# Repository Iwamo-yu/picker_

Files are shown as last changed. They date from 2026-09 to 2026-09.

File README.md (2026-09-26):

<!-- GENERATED from README.src.md by cad/render_docs.py - edit the source, not this file -->
# picker_: external XYZ capillary picker for an Evident/Olympus IX73

Stage 1 is a **spatial and mechanical feasibility study**: architecture, placement, travel, actuator stacking, capillary approach, interference with the microscope, and 96-well compatibility. There is no control software and there are no manufacturing drawings yet.

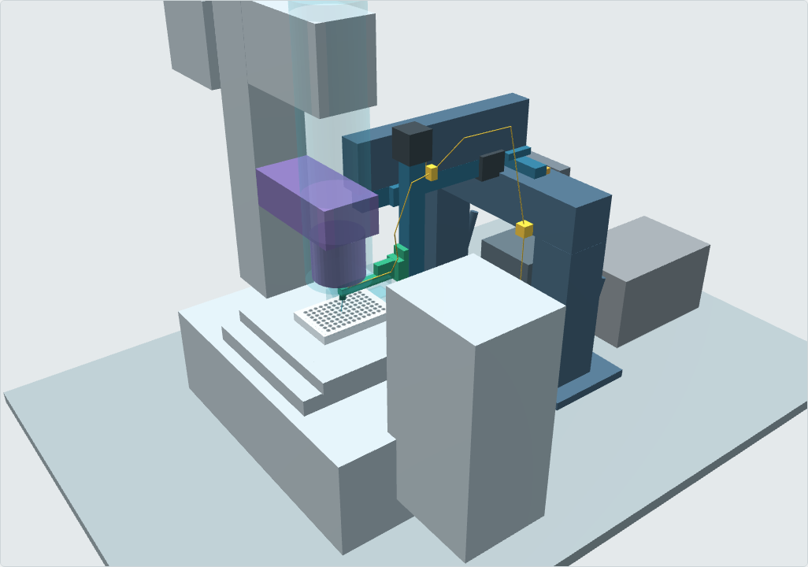
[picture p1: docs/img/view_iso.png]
isometric


## Answer to the main question

> *What is the cleanest mechanically robust way to place an external XYZ capillary picker around an IX73 so that it reliably reaches all wells of a standard 96-well plate without interfering with the microscope?*

**Provisional baseline: workflow W-B plus a side-tower picker.**

- **Workflow W-B.** The IX73 stage, motorised with ≥ 99 × 63 mm travel, brings each source and destination well to the optical axis, so **every pick and dispense is observed** (96/96). This is decision D1; see `docs/09_workflow_D1.md`.
- **Picker.** A side tower bolted to the optical table on the right of the IX73. It is a local XYZ manipulator (100 × 30 × 50 mm, Z with a 1 mm-lead ball screw) whose Z carriage holds a **thin dog-leg arm (120 mm) that reaches under the condenser to a near-vertical (8°) glass capillary**.
- **Independence from the microscope.** Nothing touches the microscope, and the frame unbolts without affecting IX73 alignment.

The stage-fixed alternative **W-A** is kept in the same CAD. Its picker covers the whole plate (150 × 100 mm, arm 180 mm) but observes only 1 well per stage setting.

The layout follows from three constraints found and quantified in this study:

1. **The 96-well limits the angle.** A 1.0 mm capillary reaches the bottom centre of a Corning 7007 U-bottom well (rim Ø6.86 mm, depth 11.30 mm) only within **14.8° of vertical**. At 30° it stops 4.9 mm below the rim, and at 45° 2.7 mm. So 30° and 45° reach **0/96 wells**, whatever the condenser.
2. **A near-vertical capillary must share the optical axis with the condenser.** That fits only under a long-working-distance condenser (**IX-ULWCD, WD 73 mm → 96/96 wells** in W-B, 96/96 in W-A) or with the illumination column tilted back. The IX2-LWUCD (WD 27 mm) and IX2-MLWCD (WD 45 mm) block most positions.
3. **Only the well on the optical axis is seen.** Observed picking of all 96 wells therefore needs the stage to move them there. Evident's IX3-SSU (76 × 52 mm) reaches only 48/96. The manual IX3-SVR (114 × 75) and 120 × 80 motorised stages reach 96/96.

**V1 scope.** V1 supports one plate SKU, **Corning 7007** (96-well U-bottom, no lid during picking), with the 8° head. A target is accepted within 0.5 mm of the well-bottom centre (`docs/09_workflow_D1.md`). Other plates (48-well (Corning 3548), 24-well (Corning 3524), 12-well (Corning 3513), 6-well (Corning 3516)) and their angle blocks are experimental.

**Safe-Z corridor and one Z reference.** The stage moves only while the tip is inside a corridor between the moving plate/stage features and the condenser (19.35–22.18 mm for V1). One physical Z reference switch serves every head (`docs/03_architecture.md` §5).

**Freeze gate.** The condenser outline, stage height and eyepiece envelope are placeholders, because no IX73, condenser or motorised-stage drawing could be retrieved. The clearances near the condenser (4.83–5 mm) are **provisional, not design evidence**. Nothing is frozen until the 10 items M1, M3, M4, M6, M7, M8, M10, M15, M19, M23 are measured (`docs/05_measurement_checklist.md`).

## Deliverables

| # | Required output | File |
|---|---|---|
| 1 | Editable parametric CAD source | `cad/params.py` (all dimensions with provenance), `cad/model.py` (build123d/OpenCascade) |
| 2 | STEP assembly | `cad/out/assembly_WB_R08_IX-ULWCD.step` (baseline W-B); `assembly_WA_{R08,V00,V30,V45}_IX-ULWCD.step` (W-A and angle comparison); `cad/out/zones_{WA,WB}_IX-ULWCD.step` (travel, safe-Z, keep-out, light cone) |
| 3 | Visual CAD preview | `viewer/ix73_picker_viewer.html`, interactive and self-contained (pick a well, angle, condenser; colour by data confidence) |
| 4–7 | Isometric / top / side / front views | 3D renders in `docs/img/view_{iso,top,front,side,head}.png`; dimensioned views in `docs/img/dim_{top,front,side}.png/.svg` |
| 8 | Travel-envelope visualisation | `docs/img/dim_top.png` (tip XY travel over all 96 wells), zones in the viewer and STEP |
| 9 | Collision / interference notes | `docs/02_approach_angle_study.md` §Collision notes; `docs/generated_analysis_tables.md` |
| 10 | 0° / 30° / 45° (+8°) comparison | `docs/02_approach_angle_study.md`, `docs/img/approach_angles.png` |
| 11 | Actuator architecture comparison | `docs/04_actuator_comparison.md` |
| 12 | Recommended overall architecture | `docs/03_architecture.md`; workflow decision D1: `docs/09_workflow_D1.md`, `docs/img/d1_workflows.png` |
| 13 | Missing IX73 measurements | `docs/05_measurement_checklist.md` |
| 14 | Source manifest | `docs/source_manifest.md`, `references/fetch_references.sh` |
| 15 | Electrical block diagram | `docs/06_electrical.md`, `docs/img/electrical_block_diagram.png` |
| 16 | Assumptions | `docs/07_assumptions_and_open_items.md` |
| 17 | Items NOT to finalise yet | `docs/07_assumptions_and_open_items.md` |
| – | Capillary sizing for 100 µm – 1 mm objects | `docs/08_capillary_sizing.md` |
| – | Plate formats (6–96 well) and exchangeable angle blocks (8° / 20° / 30°) | `docs/10_plate_formats_angle_blocks.md` |
| – | Pre-assembly actions (measure / decide / order / fabricate, Japanese) | `docs/11_pre_assembly_actions_ja.md` |
| – | Parts candidates (42 items, from web excerpts; not an order list) | `docs/12_parts_candidates.md`, `docs/parts/candidates.csv`, `docs/parts/research_notes.md` |
| – | Japanese assembly guide (auto-updated) | `docs/assembly_ja/assembly_guide_ja.html` (`python tools/build_all.py`) |
| – | Literature review (5 papers) | `docs/01_literature_review.md` |
| – | Functional diagram (pump → tubing → capillary; PC → XYZ) | `docs/img/functional_diagram.png` |

## Data confidence

Every dimension in `cad/params.py` carries a status (its origin) and, separately, a verification level (`params.verification()`: measured / official file / file retrieved / secondary source / search excerpt / not verified / placeholder / design). The viewer has a DATA ORIGIN mode and a VERIFICATION mode; the dimensioned drawings use the origin colour code:

- **STD / MFR** (green): ANSI/SLAS standards, Evident / Corning / THK / MISUMI / Oriental data.
- **DER / DES** (blue): derived or chosen in this study.
- **APX** (amber): catalogue-class envelope, not a frozen part.
- **PH** (red, hatched): placeholder. Must be measured on the real IX73.

The network policy of the authoring session blocked Zenodo, the publishers, Evident, SLAS and the component vendors. Their values come from search-result excerpts, cross-checked where possible, and are marked as such in the manifest. The two SpheroidPicker GitHub repositories were downloaded and read.

## Rebuild

```bash
pip install build123d matplotlib numpy markdown pytest
python -m pytest tests     # light geometry tests (also run in CI, .github/workflows/check.yml)
python cad/model.py        # STEP + STL + parts.json          (~10 s)
python cad/analysis.py     # well access, light obstruction, clearance sweeps (~10 min)
python cad/views.py        # dimensioned views + diagrams
python cad/render_docs.py  # README.md + docs/*.md from README.src.md + docs/src/*.md
python viewer/build_viewer.py
# or all of the above plus the assembly-guide renders:
python tools/build_all.py            # --fast skips the 8-min clearance sweep
```

`cad/params.py` is the **single source of truth**. Documents are written as templates (`README.src.md`, `docs/src/*.md`) with `{{ KEY }}` numbers from `cad/keynums.py`; edit the templates, never the rendered files. `python cad/render_docs.py --check` fails if a rendered file is stale. Change any value in `params.py` (for example, replace a `PH` with a measured value), rerun, and every figure, table and document number updates.

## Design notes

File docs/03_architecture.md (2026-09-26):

<!-- GENERATED from docs/src/03_architecture.md by cad/render_docs.py - edit the source, not this file -->
# Recommended overall architecture (stage 1, not frozen)

## 1. Recommendation

**Provisional baseline (after D1, see `09_workflow_D1.md`): workflow W-B.** The IX73 stage (motorised, ≥ 99 × 63 mm travel) brings each source and destination well to the optical axis, and the picker works locally at the axis.

The picker itself is a **side tower on the right of the IX73, bolted to the optical table**:

- a fixed Y beam on two posts;
- a Y stage carrying a cantilevered X stage;
- the X stage carrying the Z stage;
- the Z stage carrying a thin dog-leg arm that reaches under an IX-ULWCD condenser to a near-vertical (8°) capillary.

The same frame concept serves W-A (stage fixed) with longer travel and a longer arm. Both are kept in the model. The numbers below are for **W-B unless marked W-A**.

It is the cleanest robust layout for three reasons, each backed by the model:

1. **Only one thin element enters the optical-axis zone.** The arm is 12 × 12 mm for its first 60 mm (W-A: 120 mm). The tall Z actuator stays outside the condenser keep-out in every position, and the moving system clears the IX-ULWCD at all 96 wells at pick height and at safe-Z in both workflows (`09_workflow_D1.md`, `generated_analysis_tables.md`).
2. **The frame avoids every side of the IX73 that is used or unknown.** The operator side and eyepieces (front), the illumination pillar and lamp (rear) and the camera port (left, assumed) all stay clear. The tower axis is 206 mm clear of the body side (W-A: 246 mm), and nothing touches the microscope or its stage.
3. **The stiff, fixed parts are the long ones.** The Y beam is supported at both ends. The cantilevers are the X support beam and the arm (120 mm in W-B, 180 mm in W-A). Both deflect repeatably, and the image calibration absorbs the static sag.

**V1 scope.** V1 supports one plate SKU, **Corning 7007** (96-well U-bottom), with the 8° head (R08). The other plates (48-well (Corning 3548), 24-well (Corning 3524), 12-well (Corning 3513), 6-well (Corning 3516)) and their angle blocks are **experimental** and are not part of the V1 acceptance (`09_workflow_D1.md`).

**Nothing here is frozen** until the 10 freeze-gate items M1, M3, M4, M6, M7, M8, M10, M15, M19, M23 are measured (`09_workflow_D1.md`, freeze gate).

## 2. What is fixed and what moves

| Item | Group | Mounted on | Moves with | Mass carried (estimate, ±30 %) |
|---|---|---|---|---|
| Optical table, IX73, stage, plate, condenser | fixed | – | – | – |
| Base plate (15 mm Al), 2 posts (80 × 80), Y beam (80 × 80), diagonal braces | fixed | table | – | – |
| Y actuator body + motor + home switch, Y cable chain, tubing fixed clamp | fixed | Y beam | – | – |
| Y carriage, X support beam (40 × 80 min.), X actuator + motor + switch, X cable chain | **Y** | Y carriage | Y | **Y carriage carries ≈4.0 kg (W-B, incl. X and Z groups)** |
| X carriage bracket, Z actuator + motor + Z reference switch, tubing clamp #2 | **X** | X carriage | X, Y | **X carriage carries ≈1.3 kg** |
| Z carriage, kinematic break-away mount, dog-leg arm, collet holder, capillary, first 0.3 m of tubing | **Z** | Z carriage | X, Y, Z | **Z carriage carries ≈0.31 kg** |
| Syringe pump (Harvard/Tecan), controller, 24 V PSU | fixed, off-frame | table/shelf | – | – |

The masses come from `params.MASS_APX` (approximate per-part masses for width-20–26 class ball-screw stages with NEMA17 motors) summed over the CAD parts each carriage carries. They are not catalogue values and must be recomputed once part numbers are chosen.

## 3. Axis stacking and travel

Order from the table up: **Y (fixed on beam) → X (cantilever towards the axis) → Z (vertical) → arm → holder → capillary.**

Two different lengths are used throughout, and they are not interchangeable. **Tip travel** is the range the capillary tip must cover. **Actuator stroke** is the catalogue stroke of the linear stage that is bought; it is at least the tip travel and is anchored at the inner (X), front (Y) and lower (Z) end, so the extra stroke grows away from the microscope.

| Axis | W-B tip travel | W-B actuator stroke | W-A tip travel | W-A actuator stroke | Why |
|---|---|---|---|---|---|
| X | **100 mm** (tip -15…+85) | 110 mm | 150 mm | 150 mm | W-B: local calibration ±15 mm plus park / capillary change outside the condenser keep-out. W-A: 99 mm well span + 25.5 mm per side |
| Y | **30 mm** | 50 mm | 100 mm | 100 mm | W-B: local calibration. W-A: 63 mm span + 18.5 mm per side |
| Z | **50 mm** | 80 mm | 50 mm | 80 mm | pick height 3.35 → safe-Z corridor → reference switch → park-only top (capillary change) |

Why Y is the fixed axis and X the cantilever: the side tower gives a naturally long, twice-supported beam in Y. X must reach from the tower to the plate anyway. Swapping them would cantilever the *fixed* beam over the microscope.

## 4. Reaching all 96 wells

- **W-B (baseline).** The stage brings each well to the axis. With the IX3-SVR or a 120 × 80 motorised stage, all 96 wells can be picked *and observed*. The sweep translates plate and stage for every well: 96/96 clear at pick height, 96/96 at safe-Z. The stage moves only while the tip is inside the **safe-Z corridor** (§5). The IX3-SSU (76 × 52) reaches only 48/96.
- **W-A.** Tip travel 150 × 100 covers the 99 × 63 mm well field (96/96 in the sweep), but only 1 well is observed per stage setting. The rest are picked or dispensed blind unless an overview camera is added.

## 5. Z axis: low backlash and no drop on power loss

- **Screw.** Ball screw, lead 1 mm (THK KR20 class, S30), or TR8×2 *single-start, 2 mm lead* in the fallback architecture. Never the common Tr8×8(P2) four-start (8 mm lead), which can back-drive under load (S35).
- **Holding without power.** Back-driving torque from the Z load is T = F·l·η/(2π). With F ≈ 3 N (0.3 kg), l = 1 mm and η ≈ 0.8, T ≈ 0.4 mN·m. A NEMA17's unpowered detent torque is typically about 10–20 mN·m (catalogue class, to be confirmed for the chosen motor), a margin of roughly 25–50×. With a TR8×2 bronze nut, the lead angle (≈5.2° at 7 mm pitch diameter) is below the friction angle (≈6–11° for μ = 0.1–0.2), so the screw is nominally self-locking. Vibration can still creep a marginal self-locking screw.
- **Conclusion.** No brake and no counterbalance are needed at this Z load. Add a brake (for example the Oriental DRS2 brake option, S32) if the holding ratio (motor detent torque ÷ back-driving torque) falls below about 10×. That happens with a Z group above about 1 kg on a 2 mm lead, or with any lead ≥ 5 mm.
- **Resolution.** 1 mm lead / 200 full steps = 5 µm per full step, and 16× microstepping gives 0.31 µm commanded increments. Microstep linearity limits real incremental accuracy to a fraction of a full step, which is sufficient for the ≤5 µm command and 10–20 µm repeatability targets.
- **One physical Z reference.** There is exactly one Z reference switch, fixed on the Z body. It trips when the arm bottom reaches 59.7 mm above the stage datum, i.e. with the head top 2 mm below the lowest condenser front over all supported plates (74.0 mm). Because the holder top sits at the same place on the arm for every angle block, the same switch serves every head; only the tip height at the reference changes (tip at 22.13 mm for R08).
- **Safe-Z corridor.** While the stage moves (W-B) or the picker moves in XY near the axis, the tip must lie in a corridor. Its **lower bound** is the highest moving plate or stage feature plus 5 mm (plate top, or plate-holder clips `STAGE_CLIP_TOP`, M3). Its **upper bound** is the tip height at which the head top is 2 mm under the condenser front. If a configuration has no corridor (upper ≤ lower), it is rejected by the build (`tools/build_all.py --check`). Current values (`generated_analysis_tables.md` §5b):

| Head | Plate | Scope | Lower (tip) | Upper (tip) | Width | Tip at Z reference | Status |
|---|---|---|---|---|---|---|---|
| R08 | 96 U-bottom | V1 | 19.35 | 22.18 | 2.83 | 22.13 | OK |
| V20 | 12-well | experimental | 25.50 | 27.17 | 1.67 | 27.17 | narrow (< 2 mm) |
| V30 | 6-well | experimental | 25.40 | 27.59 | 2.19 | 27.59 | OK |
| V00 | 96 U-bottom | comparison | 19.35 | 21.75 | 2.40 | 21.70 | OK |
| V45 | 96 U-bottom | comparison | 19.35 | 34.64 | 15.29 | 34.59 | OK |

- **Homing.** Z up to the reference switch (this position is inside the corridor), then X to park, then Y. Z goes above the reference only at park (capillary change). The top of the Z stroke is not a safe position near the optical axis.
- **Approach.** Move fast to safe-Z (19.35), then to a pre-contact height about 0.5 mm above the stored well bottom, then land at about 10 µm/s (S23) over the last ~50 µm to the stand-off height (per plate × block × class, `10_…`). A 0.5 mm slow zone would take 50 s per landing, so the slow zone is kept short and the bottom height is calibrated per plate.

## 5b. Stage centring and carriage moments

**Stage centring (W-B).** Every well of the V1 plate reaches the optical axis only if the stage travel centre and the plate position in the holder are within these limits of the axis (`STAGE_AXIS_OFFSET` + `PLATE_HOLDER_OFFSET`, both placeholders until M4 is measured):

| Stage | Travel X × Y | Allowed centring offset X / Y | Current offset | Pass |
|---|---|---|---|---|
| IX3-SVR (manual) | 114 × 75 | ±7.5 / ±6.0 mm | 0.0, 0.0 (PH) | yes |
| IX3-SSU (ultrasonic, motorised) | 76 × 52 | none: travel short by 23 × 11 mm | 0.0, 0.0 (PH) | **no** |
| Maerzhaeuser SCAN IM for IX73 | 120 × 80 | ±10.5 / ±8.5 mm | 0.0, 0.0 (PH) | yes |

**Carriage moments.** Rigid-body static moment plus the moment from 0.5 m/s² acceleration, about each carriage reference, with approximate masses (`params.MASS_APX`). Enter the catalogue allowable moments (`ALLOWABLE_MOMENTS`) once the actuators are chosen; until then the column reads "not entered".

| Carriage | Carried mass (APX) | COM offset from carriage x/y/z | Static + accel. moment Mx, My, Mz (abs.) | Largest | Catalogue allowable |
|---|---|---|---|---|---|
| Z | 0.31 kg | -38 / -0 / -7 mm | 0.00, 0.12, 0.00 N·m | 0.12 N·m | not entered |
| X | 1.34 kg | -13 / -23 / -20 mm | 0.30, 0.19, 0.02 N·m | 0.30 N·m | not entered |
| Y | 3.95 kg | -180 / -9 / 3 mm | 0.36, 6.97, 0.36 N·m | 6.97 N·m | not entered |

The Y carriage carries the X beam and the cantilevered X/Z stack, so it sees the largest moment (≈7.0 N·m). A width-20 class guide may be marginal; compare with the catalogue MY/MP ratings before ordering.

## 6. Capillary holder concept

The holder is a **collet** (split collet with a tapered nut, sized per capillary OD) in a Ø10 × 14 mm envelope, with these features:

- A screw-set **depth stop** above the capillary gives adjustable insertion (default 10 mm grip, 30 mm exposed).
- A side or top liquid port with an O-ring seal on the capillary end-face. The seal is separate from the clamping, so it does not act as friction-only clamping.
- The holder sits in a **V-block seat on the arm** with a flat and a clamp screw. This is the mechanically defined reference surface.
- **Angle** is set by an exchangeable angle block (8° / 20° / 30°) between the kinematic mount and the holder seat: two dowels and one clamp screw. Each plate format has its own block and exposed length (`10_plate_formats_angle_blocks.md`).
- **Tip reproducibility.** The collet and depth stop give roughly ±0.1–0.2 mm (estimate). The real µm-level registration comes from the image-based 3-point re-calibration after every change (S28). The mechanics therefore need only be *stable after clamping*, not µm-reproducible between capillaries.
- **Other ODs**: objects of 100 µm – 1 mm need three capillary classes (OD 1.0 / 1.5 / 2.0; see `08_capillary_sizing.md`). They are handled by swapping the collet insert only, and all keep ≥0.87 mm rim clearance at 8°. The arm, seat and fluid port stay the same.

Commercial alternative: a patch-clamp-style pipette holder with a side port (for example, the Warner holder catalogue in the search results). Many of these clamp with O-rings, which is friction-only and was rejected as the primary fixation. One can be used with a custom depth-stop adapter.

## 7. Tubing and cable routing

**Tubing.** Use PTFE/FEP 1/16" OD (bore to suit, liquid-filled), with no drag chain. Route:

1. Holder top → along the side of the arm, in a clip groove, not on top (it is the closest item to the condenser).
2. Clamp #1 on the Z carriage.
3. Z service loop to clamp #2 on the Z body (X group).
4. X/Y service loop, hung from the X support beam, to the fixed clamp on the frame post.
5. Down the post to the pump on the table (about 1.2 m in total).

Each loop takes the full stroke with a bend radius of at least 25 mm (PTFE kink limit; to be checked for the chosen tubing). Keep the pump, any pinch valve and any pressure tee on the fixed side.

**Cables.** X/Y/Z motor and switch cables leave on the rear (+Y) side of the moving groups and run in two small cable chains (X on the Y group, Y on the frame). That keeps them physically separated from the tubing, which runs on the front (−Y) side. Motor cables should be shielded and separate from the switch cables in the chain.

## 8. Alternatives considered

| Alternative | Verdict | Reason |
|---|---|---|
| Front bridge (beam along X in front of the stage) | rejected | Sits in the eyepiece / observation-tube envelope and the operator's hand space. The eyepiece position is unknown (M12). |
| Rear bridge | rejected | The illumination pillar and lamp housing occupy the rear. |
| Full gantry over the microscope | rejected | The beam must pass above the condenser carrier, which makes Z very long and compliant. |
| Straight holder (no dog-leg) at 30–45° | rejected | Cannot reach 96-well bottoms (`02_…`). |
| **Motorised IX73 stage + short-travel picker (W-B)** | **baseline** | Follows the CellSorter/NanoPick pattern (S22, S24). Every pick and dispense is observed; smaller and stiffer; needs a motorised stage ≥ 99 × 63 mm (not the IX3-SSU). |
| Stage fixed, picker covers the plate (W-A) | kept as alternative | Reaches all wells but observes only the one on the axis; needs an overview camera or blind operation. |
| Pillar tilted back + vertical capillary + fixed LED ring illumination | valid fallback | Removes the condenser conflict entirely. It costs Köhler brightfield during the pick and needs an LED mounted on the frame, not on the head. |

## 9. Alignment and locking interfaces (custom parts that add value)

- **Base plate to table.** Slotted holes on the table grid (M6/25 mm or ¼-20/1", M16). Gives ±15 mm X/Y and ±2° yaw, locked with 6 bolts.
- **Beam height on posts.** Vertical slots plus a jack screw give ±20 mm to match the real stage height (M1). Two clamp bolts per post.
- **X-axis squareness to the plate rows.** Not adjusted mechanically; absorbed by the image calibration (affine transform).
- **Capillary angle.** Exchangeable angle blocks (8° / 20° / 30°), doweled; re-calibrate by image after each change.
- **Removability.** Unbolt the base plate: the IX73 is untouched and its alignment unchanged. Re-installing needs only re-running the image calibration.

## 10. Answers to the system-level questions

| Question | Answer (model reference pose) |
|---|---|
| Where does the gantry sit relative to the IX73? | Right-hand side; tower axis at x = +368 mm (W-A: +408) from the optical axis; posts at y = -115 and +215 mm (W-A: -150 / +230); on its own base plate on the table. |
| Which parts move / stay fixed? | §2 table. The plate and stage move in W-B, driven by the IX73 stage, not by the picker. |
| Moving mass per axis? | Y ≈2.5–3.0 kg (W-B) / 3.0–3.5 kg (W-A), X ≈1.2–1.4 kg, Z ≈0.25–0.35 kg (estimates). |
| How does it reach all 96 wells? | W-B: the stage brings each well to the axis (96/96 observed). W-A: picker travel 150 × 100 (1 observed). |
| Where does the capillary enter the plate? | Vertically from above with an 8° lean towards +X. The holder nose stays ≈19 mm above the plate top at pick height. |
| Where does the tubing leave the head? | Holder top → side of the arm → clamp on the Z carriage (outboard, x ≈ tip + 120 mm). |
| Likely collision regions? | Condenser front (arm and tubing, 4.83 mm at safe-Z with a placeholder condenser); condenser carrier arm vs X support beam (placeholder); well rims (angle); lid; in W-B, the plate moving under the tip if the stage moves below safe-Z. |
| How does the condenser constrain the angle? | Indirectly: the wells force near-vertical, so the capillary must sit below the condenser. With the current head it needs a condenser front ≥ about 70 mm above the well bottom (IX-ULWCD, WD 73 mm) for a 2 mm margin, or the column tilted back. |
| Free space needed around the microscope? | Right side: from the body side (x = 161.5) to x ≈ +458 (W-B) / +498 (W-A) for the frame, plus the pump and controller beyond, if placed there. Nothing on the front, left or rear. |
| Which dimensions still need measuring? | Freeze gate: M1, M3, M4, M6, M7, M8, M10, M15, M19, M23 (`05_measurement_checklist.md`). |

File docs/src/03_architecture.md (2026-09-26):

# Recommended overall architecture (stage 1, not frozen)

## 1. Recommendation

**Provisional baseline (after D1, see `09_workflow_D1.md`): workflow W-B.** The IX73 stage (motorised, ≥ 99 × 63 mm travel) brings each source and destination well to the optical axis, and the picker works locally at the axis.

The picker itself is a **side tower on the right of the IX73, bolted to the optical table**:

- a fixed Y beam on two posts;
- a Y stage carrying a cantilevered X stage;
- the X stage carrying the Z stage;
- the Z stage carrying a thin dog-leg arm that reaches under an IX-ULWCD condenser to a near-vertical (8°) capillary.

The same frame concept serves W-A (stage fixed) with longer travel and a longer arm. Both are kept in the model. The numbers below are for **W-B unless marked W-A**.

It is the cleanest robust layout for three reasons, each backed by the model:

1. **Only one thin element enters the optical-axis zone.** The arm is {{ARM_T_TXT}} for its first {{WB_THIN_L}} mm (W-A: {{WA_THIN_L}} mm). The tall Z actuator stays outside the condenser keep-out in every position, and the moving system clears the IX-ULWCD at all 96 wells at pick height and at safe-Z in both workflows (`09_workflow_D1.md`, `generated_analysis_tables.md`).
2. **The frame avoids every side of the IX73 that is used or unknown.** The operator side and eyepieces (front), the illumination pillar and lamp (rear) and the camera port (left, assumed) all stay clear. The tower axis is {{WB_GAP:.0f}} mm clear of the body side (W-A: {{WA_GAP:.0f}} mm), and nothing touches the microscope or its stage.
3. **The stiff, fixed parts are the long ones.** The Y beam is supported at both ends. The cantilevers are the X support beam and the arm ({{WB_ARM_L}} mm in W-B, {{WA_ARM_L}} mm in W-A). Both deflect repeatably, and the image calibration absorbs the static sag.

**V1 scope.** V1 supports one plate SKU, **{{V1_PLATE_SKU}}** (96-well U-bottom), with the {{V1_THETA:.0f}}° head ({{V1_HEAD}}). The other plates ({{EXPERIMENTAL_PLATES}}) and their angle blocks are **experimental** and are not part of the V1 acceptance (`09_workflow_D1.md`).

**Nothing here is frozen** until the {{FREEZE_GATE_N}} freeze-gate items {{FREEZE_GATE}} are measured (`09_workflow_D1.md`, freeze gate).

## 2. What is fixed and what moves

| Item | Group | Mounted on | Moves with | Mass carried (estimate, ±30 %) |
|---|---|---|---|---|
| Optical table, IX73, stage, plate, condenser | fixed | – | – | – |
| Base plate (15 mm Al), 2 posts (80 × 80), Y beam (80 × 80), diagonal braces | fixed | table | – | – |
| Y actuator body + motor + home switch, Y cable chain, tubing fixed clamp | fixed | Y beam | – | – |
| Y carriage, X support beam (40 × 80 min.), X actuator + motor + switch, X cable chain | **Y** | Y carriage | Y | **Y carriage carries ≈{{MASS_Y:.1f}} kg (W-B, incl. X and Z groups)** |
| X carriage bracket, Z actuator + motor + Z reference switch, tubing clamp #2 | **X** | X carriage | X, Y | **X carriage carries ≈{{MASS_X:.1f}} kg** |
| Z carriage, kinematic break-away mount, dog-leg arm, collet holder, capillary, first 0.3 m of tubing | **Z** | Z carriage | X, Y, Z | **Z carriage carries ≈{{MASS_Z:.2f}} kg** |
| Syringe pump (Harvard/Tecan), controller, 24 V PSU | fixed, off-frame | table/shelf | – | – |

The masses come from `params.MASS_APX` (approximate per-part masses for width-20–26 class ball-screw stages with NEMA17 motors) summed over the CAD parts each carriage carries. They are not catalogue values and must be recomputed once part numbers are chosen.

## 3. Axis stacking and travel

Order from the table up: **Y (fixed on beam) → X (cantilever towards the axis) → Z (vertical) → arm → holder → capillary.**

Two different lengths are used throughout, and they are not interchangeable. **Tip travel** is the range the capillary tip must cover. **Actuator stroke** is the catalogue stroke of the linear stage that is bought; it is at least the tip travel and is anchored at the inner (X), front (Y) and lower (Z) end, so the extra stroke grows away from the microscope.

| Axis | W-B tip travel | W-B actuator stroke | W-A tip travel | W-A actuator stroke | Why |
|---|---|---|---|---|---|
| X | **{{WB_TRAVEL_X}} mm** (tip {{WB_X_MIN}}…+{{WB_X_MAX}}) | {{WB_STROKE_X:.0f}} mm | {{WA_TRAVEL_X}} mm | {{WA_STROKE_X:.0f}} mm | W-B: local calibration ±15 mm plus park / capillary change outside the condenser keep-out. W-A: 99 mm well span + 25.5 mm per side |
| Y | **{{WB_TRAVEL_Y}} mm** | {{WB_STROKE_Y:.0f}} mm | {{WA_TRAVEL_Y}} mm | {{WA_STROKE_Y:.0f}} mm | W-B: local calibration. W-A: 63 mm span + 18.5 mm per side |
| Z | **{{WB_TRAVEL_Z}} mm** | {{WB_STROKE_Z:.0f}} mm | {{WA_TRAVEL_Z}} mm | {{WA_STROKE_Z:.0f}} mm | pick height {{Z_PICK:.2f}} → safe-Z corridor → reference switch → park-only top (capillary change) |

Why Y is the fixed axis and X the cantilever: the side tower gives a naturally long, twice-supported beam in Y. X must reach from the tower to the plate anyway. Swapping them would cantilever the *fixed* beam over the microscope.

## 4. Reaching all 96 wells

- **W-B (baseline).** The stage brings each well to the axis. With the IX3-SVR or a 120 × 80 motorised stage, all 96 wells can be picked *and observed*. The sweep translates plate and stage for every well: {{SW_WB_R08_ULWCD_PICK}}/96 clear at pick height, {{SW_WB_R08_ULWCD_SAFE}}/96 at safe-Z. The stage moves only while the tip is inside the **safe-Z corridor** (§5). The IX3-SSU (76 × 52) reaches only {{D1_WB_SSU_WELLS}}/96.
- **W-A.** Tip travel {{WA_TRAVEL_X}} × {{WA_TRAVEL_Y}} covers the 99 × 63 mm well field ({{SW_WA_R08_ULWCD_PICK}}/96 in the sweep), but only {{D1_WA_OBSERVED}} well is observed per stage setting. The rest are picked or dispensed blind unless an overview camera is added.

## 5. Z axis: low backlash and no drop on power loss

- **Screw.** Ball screw, lead 1 mm (THK KR20 class, S30), or TR8×2 *single-start, 2 mm lead* in the fallback architecture. Never the common Tr8×8(P2) four-start (8 mm lead), which can back-drive under load (S35).
- **Holding without power.** Back-driving torque from the Z load is T = F·l·η/(2π). With F ≈ 3 N (0.3 kg), l = 1 mm and η ≈ 0.8, T ≈ 0.4 mN·m. A NEMA17's unpowered detent torque is typically about 10–20 mN·m (catalogue class, to be confirmed for the chosen motor), a margin of roughly 25–50×. With a TR8×2 bronze nut, the lead angle (≈5.2° at 7 mm pitch diameter) is below the friction angle (≈6–11° for μ = 0.1–0.2), so the screw is nominally self-locking. Vibration can still creep a marginal self-locking screw.
- **Conclusion.** No brake and no counterbalance are needed at this Z load. Add a brake (for example the Oriental DRS2 brake option, S32) if the holding ratio (motor detent torque ÷ back-driving torque) falls below about 10×. That happens with a Z group above about 1 kg on a 2 mm lead, or with any lead ≥ 5 mm.
- **Resolution.** 1 mm lead / 200 full steps = 5 µm per full step, and 16× microstepping gives 0.31 µm commanded increments. Microstep linearity limits real incremental accuracy to a fraction of a full step, which is sufficient for the ≤5 µm command and 10–20 µm repeatability targets.
- **One physical Z reference.** There is exactly one Z reference switch, fixed on the Z body. It trips when the arm bottom reaches {{Z_REF_ARM_BOTTOM:.1f}} mm above the stage datum, i.e. with the head top {{Z_REF_MARGIN:.0f}} mm below the lowest condenser front over all supported plates ({{Z_REF_HEAD_TOP:.1f}} mm). Because the holder top sits at the same place on the arm for every angle block, the same switch serves every head; only the tip height at the reference changes (tip at {{ZREF_TIP_R08:.2f}} mm for {{V1_HEAD}}).
- **Safe-Z corridor.** While the stage moves (W-B) or the picker moves in XY near the axis, the tip must lie in a corridor. Its **lower bound** is the highest moving plate or stage feature plus {{CORRIDOR_LOWER_MARGIN:.0f}} mm (plate top, or plate-holder clips `STAGE_CLIP_TOP`, M3). Its **upper bound** is the tip height at which the head top is {{MIN_MARGIN:.0f}} mm under the condenser front. If a configuration has no corridor (upper ≤ lower), it is rejected by the build (`tools/build_all.py --check`). Current values (`generated_analysis_tables.md` §5b):

{{CORR_TABLE_MD}}

- **Homing.** Z up to the reference switch (this position is inside the corridor), then X to park, then Y. Z goes above the reference only at park (capillary change). The top of the Z stroke is not a safe position near the optical axis.
- **Approach.** Move fast to safe-Z ({{SAFE_Z:.2f}}), then to a pre-contact height about 0.5 mm above the stored well bottom, then land at about 10 µm/s (S23) over the last ~50 µm to the stand-off height (per plate × block × class, `10_…`). A 0.5 mm slow zone would take 50 s per landing, so the slow zone is kept short and the bottom height is calibrated per plate.

## 5b. Stage centring and carriage moments

**Stage centring (W-B).** Every well of the V1 plate reaches the optical axis only if the stage travel centre and the plate position in the holder are within these limits of the axis (`STAGE_AXIS_OFFSET` + `PLATE_HOLDER_OFFSET`, both placeholders until M4 is measured):

{{CENTER_TABLE_MD}}

**Carriage moments.** Rigid-body static moment plus the moment from {{ACCEL:.1f}} m/s² acceleration, about each carriage reference, with approximate masses (`params.MASS_APX`). Enter the catalogue allowable moments (`ALLOWABLE_MOMENTS`) once the actuators are chosen; until then the column reads "not entered".

{{MOMENT_TABLE_MD}}

The Y carriage carries the X beam and the cantilevered X/Z stack, so it sees the largest moment (≈{{MOM_Y:.1f}} N·m). A width-20 class guide may be marginal; compare with the catalogue MY/MP ratings before ordering.

## 6. Capillary holder concept

The holder is a **collet** (split collet with a tapered nut, sized per capillary OD) in a Ø10 × 14 mm envelope, with these features:

- A screw-set **depth stop** above the capillary gives adjustable insertion (default 10 mm grip, 30 mm exposed).
- A side or top liquid port with an O-ring seal on the capillary end-face. The seal is separate from the clamping, so it does not act as friction-only clamping.
- The holder sits in a **V-block seat on the arm** with a flat and a clamp screw. This is the mechanically defined reference surface.
- **Angle** is set by an exchangeable angle block ({{ANGLE_BLOCKS_TXT}}) between the kinematic mount and the holder seat: two dowels and one clamp screw. Each plate format has its own block and exposed length (`10_plate_formats_angle_blocks.md`).
- **Tip reproducibility.** The collet and depth stop give roughly ±0.1–0.2 mm (estimate). The real µm-level registration comes from the image-based 3-point re-calibration after every change (S28). The mechanics therefore need only be *stable after clamping*, not µm-reproducible between capillaries.
- **Other ODs**: objects of 100 µm – 1 mm need three capillary classes (OD 1.0 / 1.5 / 2.0; see `08_capillary_sizing.md`). They are handled by swapping the collet insert only, and all keep ≥0.87 mm rim clearance at 8°. The arm, seat and fluid port stay the same.

Commercial alternative: a patch-clamp-style pipette holder with a side port (for example, the Warner holder catalogue in the search results). Many of these clamp with O-rings, which is friction-only and was rejected as the primary fixation. One can be used with a custom depth-stop adapter.

## 7. Tubing and cable routing

**Tubing.** Use PTFE/FEP 1/16" OD (bore to suit, liquid-filled), with no drag chain. Route:

1. Holder top → along the side of the arm, in a clip groove, not on top (it is the closest item to the condenser).
2. Clamp #1 on the Z carriage.
3. Z service loop to clamp #2 on the Z body (X group).
4. X/Y service loop, hung from the X support beam, to the fixed clamp on the frame post.
5. Down the post to the pump on the table (about 1.2 m in total).

Each loop takes the full stroke with a bend radius of at least 25 mm (PTFE kink limit; to be checked for the chosen tubing). Keep the pump, any pinch valve and any pressure tee on the fixed side.

**Cables.** X/Y/Z motor and switch cables leave on the rear (+Y) side of the moving groups and run in two small cable chains (X on the Y group, Y on the frame). That keeps them physically separated from the tubing, which runs on the front (−Y) side. Motor cables should be shielded and separate from the switch cables in the chain.

## 8. Alternatives considered

| Alternative | Verdict | Reason |
|---|---|---|
| Front bridge (beam along X in front of the stage) | rejected | Sits in the eyepiece / observation-tube envelope and the operator's hand space. The eyepiece position is unknown (M12). |
| Rear bridge | rejected | The illumination pillar and lamp housing occupy the rear. |
| Full gantry over the microscope | rejected | The beam must pass above the condenser carrier, which makes Z very long and compliant. |
| Straight holder (no dog-leg) at 30–45° | rejected | Cannot reach 96-well bottoms (`02_…`). |
| **Motorised IX73 stage + short-travel picker (W-B)** | **baseline** | Follows the CellSorter/NanoPick pattern (S22, S24). Every pick and dispense is observed; smaller and stiffer; needs a motorised stage ≥ 99 × 63 mm (not the IX3-SSU). |
| Stage fixed, picker covers the plate (W-A) | kept as alternative | Reaches all wells but observes only the one on the axis; needs an overview camera or blind operation. |
| Pillar tilted back + vertical capillary + fixed LED ring illumination | valid fallback | Removes the condenser conflict entirely. It costs Köhler brightfield during the pick and needs an LED mounted on the frame, not on the head. |

## 9. Alignment and locking interfaces (custom parts that add value)

- **Base plate to table.** Slotted holes on the table grid (M6/25 mm or ¼-20/1", M16). Gives ±15 mm X/Y and ±2° yaw, locked with 6 bolts.
- **Beam height on posts.** Vertical slots plus a jack screw give ±20 mm to match the real stage height (M1). Two clamp bolts per post.
- **X-axis squareness to the plate rows.** Not adjusted mechanically; absorbed by the image calibration (affine transform).
- **Capillary angle.** Exchangeable angle blocks ({{ANGLE_BLOCKS_TXT}}), doweled; re-calibrate by image after each change.
- **Removability.** Unbolt the base plate: the IX73 is untouched and its alignment unchanged. Re-installing needs only re-running the image calibration.

## 10. Answers to the system-level questions

| Question | Answer (model reference pose) |
|---|---|
| Where does the gantry sit relative to the IX73? | Right-hand side; tower axis at x = +{{WB_TOWER_X}} mm (W-A: +{{WA_TOWER_X}}) from the optical axis; posts at y = {{WB_POST_Y0}} and +{{WB_POST_Y1}} mm (W-A: {{WA_POST_Y0}} / +{{WA_POST_Y1}}); on its own base plate on the table. |
| Which parts move / stay fixed? | §2 table. The plate and stage move in W-B, driven by the IX73 stage, not by the picker. |
| Moving mass per axis? | Y ≈2.5–3.0 kg (W-B) / 3.0–3.5 kg (W-A), X ≈1.2–1.4 kg, Z ≈0.25–0.35 kg (estimates). |
| How does it reach all 96 wells? | W-B: the stage brings each well to the axis ({{D1_WB_OBSERVED}}/96 observed). W-A: picker travel {{WA_TRAVEL_X}} × {{WA_TRAVEL_Y}} ({{D1_WA_OBSERVED}} observed). |
| Where does the capillary enter the plate? | Vertically from above with an 8° lean towards +X. The holder nose stays ≈19 mm above the plate top at pick height. |
| Where does the tubing leave the head? | Holder top → side of the arm → clamp on the Z carriage (outboard, x ≈ tip + {{WB_ARM_L}} mm). |
| Likely collision regions? | Condenser front (arm and tubing, {{SW_WB_R08_ULWCD_SAFE_CLEAR}} mm at safe-Z with a placeholder condenser); condenser carrier arm vs X support beam (placeholder); well rims (angle); lid; in W-B, the plate moving under the tip if the stage moves below safe-Z. |
| How does the condenser constrain the angle? | Indirectly: the wells force near-vertical, so the capillary must sit below the condenser. With the current head it needs a condenser front ≥ about {{WD_REQ:.0f}} mm above the well bottom (IX-ULWCD, WD 73 mm) for a {{MIN_MARGIN:.0f}} mm margin, or the column tilted back. |
| Free space needed around the microscope? | Right side: from the body side (x = {{IX73_HALF_W}}) to x ≈ +{{WB_FOOT_X}} (W-B) / +{{WA_FOOT_X}} (W-A) for the frame, plus the pump and controller beyond, if placed there. Nothing on the front, left or rear. |
| Which dimensions still need measuring? | Freeze gate: {{FREEZE_GATE}} (`05_measurement_checklist.md`). |

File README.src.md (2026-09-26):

# picker_: external XYZ capillary picker for an Evident/Olympus IX73

Stage 1 is a **spatial and mechanical feasibility study**: architecture, placement, travel, actuator stacking, capillary approach, interference with the microscope, and 96-well compatibility. There is no control software and there are no manufacturing drawings yet.

isometric

## Answer to the main question

> *What is the cleanest mechanically robust way to place an external XYZ capillary picker around an IX73 so that it reliably reaches all wells of a standard 96-well plate without interfering with the microscope?*

**Provisional baseline: workflow W-B plus a side-tower picker.**

- **Workflow W-B.** The IX73 stage, motorised with ≥ 99 × 63 mm travel, brings each source and destination well to the optical axis, so **every pick and dispense is observed** ({{D1_WB_OBSERVED}}/96). This is decision D1; see `docs/09_workflow_D1.md`.
- **Picker.** A side tower bolted to the optical table on the right of the IX73. It is a local XYZ manipulator ({{WB_TRAVEL_X}} × {{WB_TRAVEL_Y}} × {{WB_TRAVEL_Z}} mm, Z with a 1 mm-lead ball screw) whose Z carriage holds a **thin dog-leg arm ({{WB_ARM_L}} mm) that reaches under the condenser to a near-vertical (8°) glass capillary**.
- **Independence from the microscope.** Nothing touches the microscope, and the frame unbolts without affecting IX73 alignment.

The stage-fixed alternative **W-A** is kept in the same CAD. Its picker covers the whole plate ({{WA_TRAVEL_X}} × {{WA_TRAVEL_Y}} mm, arm {{WA_ARM_L}} mm) but observes only {{D1_WA_OBSERVED}} well per stage setting.

The layout follows from three constraints found and quantified in this study:

1. **The 96-well limits the angle.** A 1.0 mm capillary reaches the bottom centre of a Corning 7007 U-bottom well (rim Ø6.86 mm, depth 11.30 mm) only within **{{MAX_ANGLE:.1f}}° of vertical**. At 30° it stops {{REACH_30:.1f}} mm below the rim, and at 45° {{REACH_45:.1f}} mm. So 30° and 45° reach **{{SW_WA_V30_ULWCD_PICK}}/96 wells**, whatever the condenser.
2. **A near-vertical capillary must share the optical axis with the condenser.** That fits only under a long-working-distance condenser (**IX-ULWCD, WD 73 mm → {{SW_WB_R08_ULWCD_PICK}}/96 wells** in W-B, {{SW_WA_R08_ULWCD_PICK}}/96 in W-A) or with the illumination column tilted back. The IX2-LWUCD (WD 27 mm) and IX2-MLWCD (WD 45 mm) block most positions.
3. **Only the well on the optical axis is seen.** Observed picking of all 96 wells therefore needs the stage to move them there. Evident's IX3-SSU (76 × 52 mm) reaches only {{D1_WB_SSU_WELLS}}/96. The manual IX3-SVR (114 × 75) and 120 × 80 motorised stages reach 96/96.

**V1 scope.** V1 supports one plate SKU, **{{V1_PLATE_SKU}}** (96-well U-bottom, no lid during picking), with the {{V1_THETA:.0f}}° head. A target is accepted within {{V1_TARGET_R:.1f}} mm of the well-bottom centre (`docs/09_workflow_D1.md`). Other plates ({{EXPERIMENTAL_PLATES}}) and their angle blocks are experimental.

**Safe-Z corridor and one Z reference.** The stage moves only while the tip is inside a corridor between the moving plate/stage features and the condenser ({{CORR_R08_LO:.2f}}–{{CORR_R08_HI:.2f}} mm for V1). One physical Z reference switch serves every head (`docs/03_architecture.md` §5).

**Freeze gate.** The condenser outline, stage height and eyepiece envelope are placeholders, because no IX73, condenser or motorised-stage drawing could be retrieved. The clearances near the condenser ({{SW_WB_R08_ULWCD_SAFE_CLEAR}}–5 mm) are **provisional, not design evidence**. Nothing is frozen until the {{FREEZE_GATE_N}} items {{FREEZE_GATE}} are measured (`docs/05_measurement_checklist.md`).

## Deliverables

| # | Required output | File |
|---|---|---|
| 1 | Editable parametric CAD source | `cad/params.py` (all dimensions with provenance), `cad/model.py` (build123d/OpenCascade) |
| 2 | STEP assembly | `cad/out/assembly_WB_R08_IX-ULWCD.step` (baseline W-B); `assembly_WA_{R08,V00,V30,V45}_IX-ULWCD.step` (W-A and angle comparison); `cad/out/zones_{WA,WB}_IX-ULWCD.step` (travel, safe-Z, keep-out, light cone) |
| 3 | Visual CAD preview | `viewer/ix73_picker_viewer.html`, interactive and self-contained (pick a well, angle, condenser; colour by data confidence) |
| 4–7 | Isometric / top / side / front views | 3D renders in `docs/img/view_{iso,top,front,side,head}.png`; dimensioned views in `docs/img/dim_{top,front,side}.png/.svg` |
| 8 | Travel-envelope visualisation | `docs/img/dim_top.png` (tip XY travel over all 96 wells), zones in the viewer and STEP |
| 9 | Collision / interference notes | `docs/02_approach_angle_study.md` §Collision notes; `docs/generated_analysis_tables.md` |
| 10 | 0° / 30° / 45° (+8°) comparison | `docs/02_approach_angle_study.md`, `docs/img/approach_angles.png` |
| 11 | Actuator architecture comparison | `docs/04_actuator_comparison.md` |
| 12 | Recommended overall architecture | `docs/03_architecture.md`; workflow decision D1: `docs/09_workflow_D1.md`, `docs/img/d1_workflows.png` |
| 13 | Missing IX73 measurements | `docs/05_measurement_checklist.md` |
| 14 | Source manifest | `docs/source_manifest.md`, `references/fetch_references.sh` |
| 15 | Electrical block diagram | `docs/06_electrical.md`, `docs/img/electrical_block_diagram.png` |
| 16 | Assumptions | `docs/07_assumptions_and_open_items.md` |
| 17 | Items NOT to finalise yet | `docs/07_assumptions_and_open_items.md` |
| – | Capillary sizing for 100 µm – 1 mm objects | `docs/08_capillary_sizing.md` |
| – | Plate formats (6–96 well) and exchangeable angle blocks ({{ANGLE_BLOCKS_TXT}}) | `docs/10_plate_formats_angle_blocks.md` |
| – | Pre-assembly actions (measure / decide / order / fabricate, Japanese) | `docs/11_pre_assembly_actions_ja.md` |
| – | Parts candidates (42 items, from web excerpts; not an order list) | `docs/12_parts_candidates.md`, `docs/parts/candidates.csv`, `docs/parts/research_notes.md` |
| – | Japanese assembly guide (auto-updated) | `docs/assembly_ja/assembly_guide_ja.html` (`python tools/build_all.py`) |
| – | Literature review (5 papers) | `docs/01_literature_review.md` |
| – | Functional diagram (pump → tubing → capillary; PC → XYZ) | `docs/img/functional_diagram.png` |

## Data confidence

Every dimension in `cad/params.py` carries a status (its origin) and, separately, a verification level (`params.verification()`: measured / official file / file retrieved / secondary source / search excerpt / not verified / placeholder / design). The viewer has a DATA ORIGIN mode and a VERIFICATION mode; the dimensioned drawings use the origin colour code:

- **STD / MFR** (green): ANSI/SLAS standards, Evident / Corning / THK / MISUMI / Oriental data.
- **DER / DES** (blue): derived or chosen in this study.
- **APX** (amber): catalogue-class envelope, not a frozen part.
- **PH** (red, hatched): placeholder. Must be measured on the real IX73.

The network policy of the authoring session blocked Zenodo, the publishers, Evident, SLAS and the component vendors. Their values come from search-result excerpts, cross-checked where possible, and are marked as such in the manifest. The two SpheroidPicker GitHub repositories were downloaded and read.

## Rebuild

```bash
pip install build123d matplotlib numpy markdown pytest
python -m pytest tests     # light geometry tests (also run in CI, .github/workflows/check.yml)
python cad/model.py        # STEP + STL + parts.json          (~10 s)
python cad/analysis.py     # well access, light obstruction, clearance sweeps (~10 min)
python cad/views.py        # dimensioned views + diagrams
python cad/render_docs.py  # README.md + docs/*.md from README.src.md + docs/src/*.md
python viewer/build_viewer.py
# or all of the above plus the assembly-guide renders:
python tools/build_all.py            # --fast skips the 8-min clearance sweep
```

`cad/params.py` is the **single source of truth**. Documents are written as templates (`README.src.md`, `docs/src/*.md`) with `{{ KEY }}` numbers from `cad/keynums.py`; edit the templates, never the rendered files. `python cad/render_docs.py --check` fails if a rendered file is stale. Change any value in `params.py` (for example, replace a `PH` with a measured value), rerun, and every figure, table and document number updates.

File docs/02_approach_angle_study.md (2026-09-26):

<!-- GENERATED from docs/src/02_approach_angle_study.md by cad/render_docs.py - edit the source, not this file -->
# Capillary approach: 0° vs 8° vs 30° vs 45°, plus collision and interference notes

Figures: `img/approach_angles.png`, `img/view_head.png`, `img/dim_front.png`. The raw numbers are in `generated_analysis_tables.md`, produced by `cad/analysis.py`.

## Conclusion

The capillary's last segment must be **near-vertical (0–12°)**. The binding constraint is the 96-well itself, not the condenser. A near-vertical capillary then has to share the space on the optical axis with the condenser. That works only if (a) the condenser has a long working distance (IX-ULWCD, WD 73 mm) and the picker reaches in with a thin horizontal "dog-leg" arm below it, or (b) the illumination column is tilted back during picking. With the IX2-LWUCD (WD 27 mm) no angle works. **8° with a dog-leg arm** is the recommended geometry for 96-well plates. The angle is set by exchangeable angle blocks (8° / 20° / 30°), one per plate format (`10_plate_formats_angle_blocks.md`), not by a continuous tilt.

## Method

Every angle uses the same external frame and the same outboard Z position, with the W-A frame (180 mm arm, picker covering the plate; the W-B frame gives the same angle results at the optical axis). Only the capillary/holder angle changes, so the comparison isolates the effect of angle. Three checks were run:

1. **Well access (analytic).** Corning 7007 U-bottom: rim Ø6.86 mm, depth 11.30 mm (S13). Capillary OD 1.0 mm, tip 0.3 mm above the well bottom.
2. **Clearance sweep (OpenCascade minimum distance).** All 96 wells at pick height and at safe-Z (the lower bound of the safe-Z corridor: highest moving plate or clip feature + 5 mm), plus a 35-point grid over the full 150 × 100 travel at safe-Z and at the top of the Z stroke. Moving parts are checked against the IX73 envelope, the condensers, the plate and the pump.
3. **Illumination obstruction (analytic).** Fraction of the condenser light cone blocked by the Ø10 holder at its nose height.

## Results

| Criterion | 0° | **8° (rec.)** | 30° | 45° |
|---|---|---|---|---|
| Rim clearance, tip at well-bottom centre | +2.93 mm | **+1.38 mm** | -3.50 mm (hits rim) | -8.28 mm (hits rim) |
| Deepest centred reach below the rim | full (11.3 mm) | **full** | 4.9 mm | 2.7 mm |
| Wells reachable at pick height, IX-ULWCD | 96/96 | **96/96** | 0/96 | 0/96 |
| Wells reachable at pick height, IX2-LWUCD | 10/96 | 16/96 | 0/96 | 0/96 |
| Wells reachable at pick height, pillar tilted back | 96/96 | **96/96** | 0/96 | 0/96 |
| Illumination blocked by holder, condenser NA 0.1 / 0.3 | 100 % / 28 % | 61 % / 28 % | 0 % / 0 % | 0 % / 0 % |
| Tip visible beside holder in transmitted light | no (coaxial) | partly | yes | yes |
| Cantilever from holder to tip (exposed glass) | 30 mm | 30 mm | 30 mm | 30 mm |
| Lateral tip compliance from tubing/drag forces | lowest | low | medium (bending ∝ sin θ) | highest |
| Tubing exit | vertical, turns into arm | same | along capillary axis, higher | lowest, near plate |
| Maximum angle for bottom-centre access | | 14.8° (no margin) | | |

**Reading the table.**

- **30° and 45° fail** for any standard 96-well plate. The shaft meets the rim long before the tip reaches the bottom. That holds whatever condenser is fitted. An angled capillary also cannot follow an object off-centre on the far side of a U-bottom.
- **0° is geometrically best** for the wells, but the holder sits coaxially above the tip. At low condenser NA it blocks the whole light cone, so transmitted-light imaging during the landing is lost.
- **8°** keeps a 1.38 mm rim margin and moves the holder about 4 mm off the axis. Including the arm, the head still blocks about a third of the NA 0.3 cone at 8° (ray test, `generated_analysis_tables.md` §2), so the image is darker during landing but the tip remains visible beside the holder. The Zhao et al. 45° mount (S23) is correct for open droplets but not for wells.

The illumination figures are an obstruction estimate, not an optical simulation. **Test M18** (a Ø10 rod at 30–45 mm above focus, 4× and 10×) decides whether the 8° block is enough for 96-well work or whether a 10–12° block should be added.

## Condenser constraint

Condenser fronts are placed at well bottom + WD, with WD from manufacturer data (S03, S04). Condenser diameter and body are **placeholders** (Ø80), so all numbers below move once M6–M8 are measured.

| Condenser | WD (MFR) | front above plate top | Result with dog-leg arm (12 mm thick) |
|---|---|---|---|
| IX2-LWUCD | 27 mm | ≈15.7 mm | arm collides at pick height near the axis: **unusable** |
| IX2-MLWCD | 45 mm | ≈33.7 mm | arm collides at pick height near the axis: **unusable** |
| **IX-ULWCD** | 73 mm | ≈61.7 mm | W-A 96/96, W-B 96/96 at pick height; minimum clearance 4.83 mm at safe-Z (tubing on the arm vs condenser front) |
| none (column tilted back) | – | – | no constraint; needs alternative illumination during picking |

## Collision and interference notes

1. **Condenser.** This is the dominant hazard. Under the IX-ULWCD the Z stroke **above the reference height is blocked near the axis**. W-A: 20 of 35 grid points at top-Z are clear; W-B: 15 of 35. In W-A the arm reaches 120 mm towards +X, so collisions also occur with the tip *outside* a simple cylinder around the axis. The control rule is therefore: **Z may go above the reference switch height only at the park position** (X ≥ park), and homing lifts Z to the reference switch first (`06_electrical.md`). Capillary changes happen at park.
2. **Arm length.** The thin section of the arm must extend from the tip by |tip x min| + condenser radius + margin: 120 mm in W-A, 60 mm in W-B (computed in `params.layout`). (During the W-A iteration, a 60 mm thin section collided at safe-Z in columns 1–3. The sweep caught it, and the rule above was derived from it.) The tall Z actuator stays outboard of the condenser in every position.
3. **Tubing on the arm.** It is the closest item to the condenser (4.83 mm). Route it along the side of the arm, not on top.
4. **Well walls.** They are the binding constraint on angle (above). The OCC sweep and the analytic check agree: 30° and 45° give 0/96.
5. **Plate lid.** The model assumes no lid. A lid adds about 2 mm (Corning 7007 is 0.650 in = 16.5 mm high with lid, against 14.35 mm without). Lid removal belongs in the workflow.
6. **Stage and plate holder clips.** These are unknown (M3). The arm underside is ≈41 mm above the stage at pick height and ≈57 mm at safe-Z, so it is not critical.
7. **Objective and turret.** They lie below the stage; the picker cannot reach them because nothing moves below z = 0. The risk is to the plate bottom, not the objective: a tip driven through a thin plate bottom would load the plate. Limit this with a firmware Z floor at the **measured** well bottom + r·sin θ + 0.1 mm per plate × block × capillary class (the lowest edge of a tilted square-cut tip), never below the bottom.
8. **Microscope frame.** The closest fixed IX73 item to the frame is the body side at x = +161.5 mm. The tower axis is at +408 mm in W-A (246 mm gap) and +368 mm in W-B (206 mm gap). The X support beam passes over the stage at z ≥ 180 mm; the condenser carrier arm is at x = ±45 mm (placeholder), and the X actuator's inner end is at x = 60 mm (20 mm beyond the condenser radius). **This gap is a placeholder result and must be re-checked after M7.**
9. **Eyepieces / observation tube.** The frame does not use the operator side. A front bridge was rejected because it would sit in the (unknown, M12) eyepiece envelope and in the operator's hand space.
10. **Break-away mount.** The arm hangs on a magnet-preloaded kinematic mount (e.g. Thorlabs KB25/M, about 16 N holding force, P12). It is a **kinematic repositioner, not a force limiter**: its release force at the tip is about 1.67 N. That protects the plate, stage and condenser from a stalled axis (below the 5 N plate limit, placeholder), but **not the capillary**, whose estimated lateral breaking force is 0.15–1.18 N (`06_electrical.md`). Treat capillaries as consumables in a crash, and re-calibrate after any detach. A compliant low-force stage at the holder is open decision D9.

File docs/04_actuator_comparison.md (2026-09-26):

<!-- GENERATED from docs/src/04_actuator_comparison.md by cad/render_docs.py - edit the source, not this file -->
# Preliminary actuator architecture comparison

Values marked (S..) come from the source manifest. Values marked ~ are typical catalogue-class figures that were **not verified in this session** and must be checked against the chosen part's datasheet before ordering.

| Criterion | **A. Industrial compact ball-screw stages** (THK KR20/KR26, MISUMI LX20/LX26, Oriental DRS2 for Z) | **B. Low-cost integrated stages** (FUYU FSL30/FSK30, generic MGN12 + SFU08/12 ball screw + NEMA17) | **C. Custom** (MGN12H rail + Tr8×2 single-start lead screw + NEMA17) |
|---|---|---|---|
| Travel availability | KR20: 30–130 mm (S30), so Z 50 mm and X 100 mm (W-B) fit; W-A's X 150 mm needs KR26/LX26; LX26: lead 2/5 mm (S31) | 50–300 mm (S33) | any |
| Repeatability | ~±0.003 mm (precision grade) to ~±0.01 mm; DRS2 ±0.003 (ground) / ±0.01 (rolled) (S32) | position accuracy 0.05 mm quoted (S33); repeatability ~±0.01–0.02, batch dependent | ~±0.01–0.02 mm with single-direction approach; depends on assembly |
| Backlash | ~≤0.02 mm, preloaded nut options | ~0.01–0.03 mm | 0.05–0.1 mm with a plain brass nut; ~0.01–0.02 with an anti-backlash POM nut (wears) |
| Lead / resolution | 1 or 2 mm, so 5–10 µm per full step | 1–5 mm typical | 2 mm, so 10 µm per full step |
| Rigidity | high: U-rail with integrated guide (S30) | medium: extruded body, small blocks | medium: depends on the base plate you design |
| Size (width class) | 20–26 mm | 30–40 mm | 27 mm carriage, plus screw offset |
| Moving mass | low–medium | medium | low |
| Assembly effort | bolt-on; motor bracket supplied | bolt-on | high: alignment of screw, rail and bearings |
| Availability (Japan) | good via MISUMI/THK/Oriental distributors | online marketplaces; lead time and QC vary | all parts common |
| Serviceability | documented, grease ports, spares | limited documentation | fully user-serviceable |
| Suitability around IX73 | best: compact bodies keep the X cantilever light and the Z envelope narrow | acceptable for Y (fixed beam); weaker as a cantilevered X | acceptable for Y; weakest for Z (backlash) |
| Typical cost (rough) | highest (~JPY 50–120k per axis) | lowest | lowest in parts, highest in labour |

## Recommendation (to be frozen only after the geometry is validated)

"Tip travel" is what the capillary tip must cover; "actuator stroke" is the catalogue stroke bought, which is at least the tip travel (`03_architecture.md` §3).

- **Z: architecture A, 1 mm lead ball screw** (THK KR20 class; tip travel 50 mm, catalogue actuator stroke 80 mm in the model), or an Oriental DRS2 guide type with brake if a closed-loop absolute axis is preferred. Z sets landing accuracy and must not drop, so this is where the money should go.
- **X: architecture A** (KR20/LX26 class, lead 1–2 mm; tip travel 100 mm in W-B → actuator stroke 110 mm, tip travel 150 mm in W-A → 150 mm). It is the cantilevered axis, so body stiffness and low mass matter most.
- **Y: A or B** (tip travel 30 mm in W-B → actuator stroke 50 mm). It is fixed on a supported beam, so a good integrated stage from B is acceptable, but its carriage carries the X and Z groups (≈4.0 kg, largest moment ≈7.0 N·m, `03_architecture.md` §5b): check the catalogue moment ratings. Choose A if one supplier and consistent documentation matter.
- **Architecture C** is kept as a comparison and fallback. It is appropriate only if lead times block A/B. In that case, use a Tr8×2 single-start screw (2 mm lead, **not** Tr8×8), an anti-backlash nut, a fixed-floating bearing arrangement, and always approach from one direction.

This mix fits the stated budget order (about JPY 200k, cost secondary) with A on X and Z. The exact part numbers are **not** frozen (see `07_…`).

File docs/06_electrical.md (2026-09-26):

<!-- GENERATED from docs/src/06_electrical.md by cad/render_docs.py - edit the source, not this file -->
# Preliminary electrical architecture (not frozen; no software in this stage)

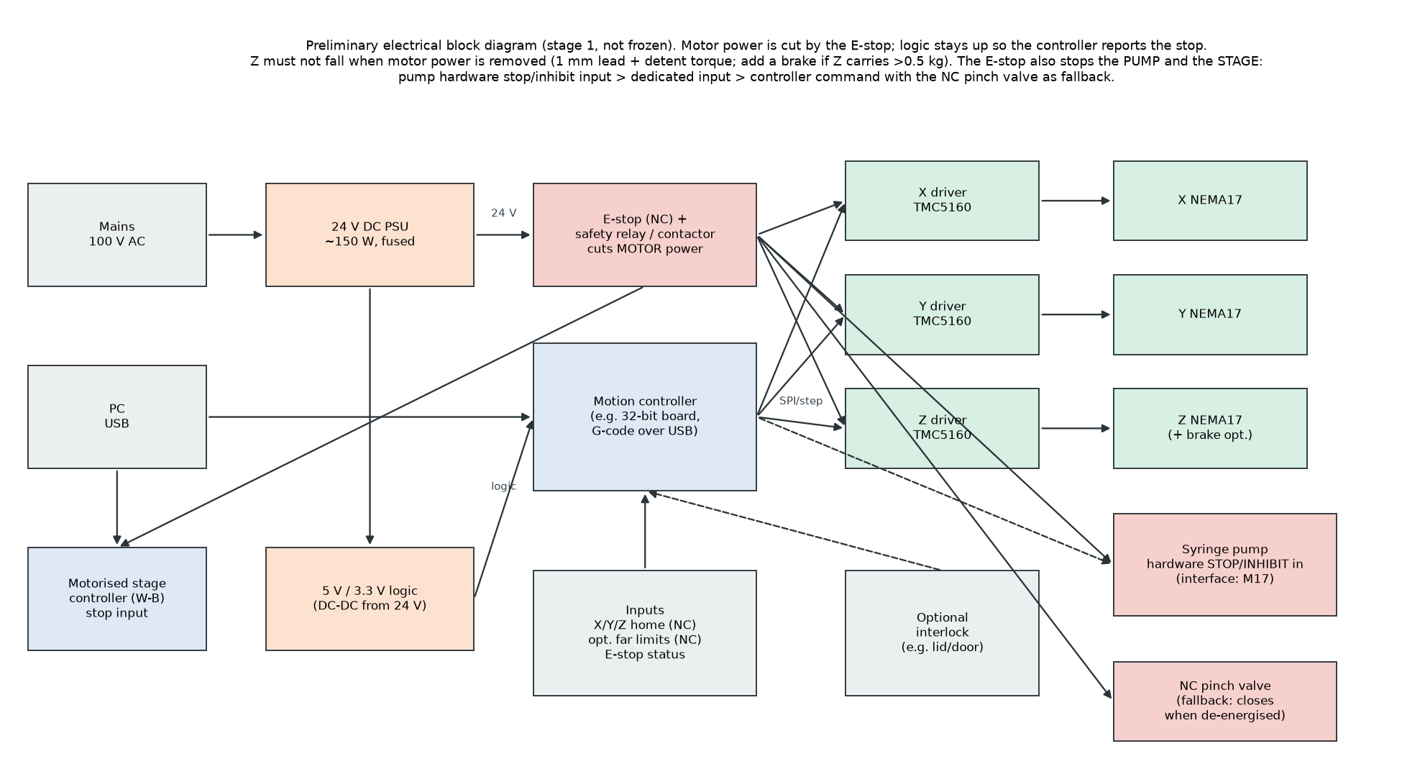
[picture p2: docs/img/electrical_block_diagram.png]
electrical block diagram


```mermaid
flowchart LR
  AC[Mains 100 V AC] --> PSU[24 V DC PSU ~150 W, fused]
  PSU --> ES[E-stop NC + safety relay / contactor<br/>cuts MOTOR power only]
  PSU --> LOGIC[5 V / 3.3 V logic]
  PC[PC - USB] --> CTL[Motion controller<br/>G-code / serial]
  LOGIC --> CTL
  ES --> DX[X driver TMC5160] & DY[Y driver TMC5160] & DZ[Z driver TMC5160]
  CTL -- SPI + step/dir --> DX & DY & DZ
  DX --> MX[X NEMA17]
  DY --> MY[Y NEMA17]
  DZ --> MZ[Z NEMA17 + optional brake]
  SW[X/Y/Z home NC<br/>optional far limits NC<br/>E-stop status] --> CTL
  IL[optional interlock] -.-> CTL
  PC -. RS-232/USB .-> PUMP[Syringe pump<br/>own PSU, off-frame]
  ES -- hardware stop / inhibit --> PUMP
  CTL -. stop command .-> PUMP
  ES -- power --> PV[NC pinch valve<br/>fallback]
  PC --> STG[Motorised stage controller W-B]
  ES -- stop input --> STG
```

The main decisions are below.

**Driver class.** TMC5160 rather than TMC2209. The TMC5160 has external MOSFETs, so it runs 24 V NEMA17s at 1.5–2 A with headroom. It has SPI configuration and diagnostics, and stealthChop gives smooth low-speed Z landing. The TMC2209 is adequate electrically for small NEMA17s, but it runs near its thermal limit at 1.5 A and is configured over UART.

**Controller.** Any PC-accessible, G-code-speaking 32-bit motion board that exposes SPI to TMC5160 drivers and ≥6 NC inputs. An industrial alternative is to use the actuator vendor's own drivers, such as the Oriental AZ driver for a DRS2 Z axis. This follows the SpheroidPicker precedent of a G-code serial controller (S28).

**Home and reference switches.** All are normally-closed (fail-safe), so a broken wire reads as "triggered".
- X: outboard end. Y: front end.
- Z: **two switches**.
  - The **reference switch** is one physical switch on the Z body. It trips when the arm bottom is at 59.7 mm above the stage datum, i.e. with the head top 2 mm below the lowest condenser front over all supported plates. It is set from M8 at installation. At that height the arm clears the condenser at every XY. Because the angle blocks change only the tip, not the arm, the same switch serves all heads; the tip lies inside each head's safe-Z corridor: 22.13 / 27.17 / 27.59 mm above the stage top for the 8° / 20° / 30° blocks (corridors in `03_architecture.md` §5).
  - The **top limit switch** is an over-travel stop only. It is *not* a safe position: near the optical axis, Z at the top drives the arm into the condenser.

**Homing order.** Z rises slowly to the reference switch (inside the corridor). X then moves to park (+85 mm, outside the condenser). Only then may Z go higher, and Y homes. After a power loss the tip may still be in a well; this order lifts it vertically out of the well without dragging it sideways and without reaching the condenser. A closed-loop absolute Z (D5, e.g. DRS2) makes this recovery independent of switches.

**Far limits.** Optional NC switches plus firmware soft limits. The actuators' own mechanical end stops are the hard limit.

**E-stop.** It removes motor power through a contactor. Logic stays powered so the controller latches and reports the fault. Z does not fall (see `03_architecture.md` §5). The E-stop must also stop **the pump and the motorised stage**, because a running pump keeps aspirating or dispensing and a moving stage drags the plate under the tip.

**Pump stop on E-stop (issue #8).** The pump keeps its own power supply, but its motion must stop on E-stop. Use the first option the chosen pump supports, in this order:

1. a **hardware stop / inhibit input** on the pump, wired to a spare NC contact of the safety relay;
2. a dedicated digital "stop" or "external trigger" input, driven by the relay;
3. a **controller stop command** over RS-232/USB **plus** a normally-closed pinch valve on the line, powered through the E-stop circuit, so the line is closed when power drops even if the command is lost.

Cutting the pump's mains is the last resort: some pumps lose their position or state and may not stop the plunger cleanly. M17 records which interface the lab's pump offers.

**Motorised stage on E-stop (W-B).** The stage controller's stop/enable input is wired to the relay the same way. If it has none, the stage motor supply is switched by the contactor.

**Restart and recovery.** Releasing the E-stop does not restart anything. The operator acknowledges the fault on the PC. The controller then re-homes Z to the reference (tip vertically out of the well), X to park, then Y. The pump is re-enabled last, after the tubing and the capillary have been inspected. A capillary that was in a well at the stop is treated as possibly broken (see break-away below).

**Break-away mount is a kinematic repositioner, not a force limiter.** The magnetic kinematic mount under the arm lets the arm come off in a crash and go back on to about the same place. It does **not** limit the force on the capillary: at a hold force of about 16 N it releases at about 1.67 N at the tip, above the estimated lateral breaking force of every capillary class (0.15–1.18 N). It does protect the plate (below 5 N, placeholder):

| Capillary | OD / ID | Lateral break force at the tip (est.) | Mount release force at the tip | Capillary protected | Plate protected |
|---|---|---|---|---|---|
| S  (100-300 um) | 1.00 / 0.58 | 0.15 N | 1.67 N | **no** | yes |
| M  (300-600 um) | 1.50 / 0.84 | 0.50 N | 1.67 N | **no** | yes |
| L  (600-800 um) | 2.00 / 1.12 | 1.18 N | 1.67 N | **no** | yes |
| L' (800-1000 um) | 2.00 / 1.56 | 0.82 N | 1.67 N | **no** | yes |

Capillaries are therefore consumables in a crash. If the capillary itself must survive, a compliant or low-force stage is needed at the holder (a spring-loaded flexure that deflects at well below 0.15 N), or current/torque-limited Z landing with contact detection. This is left open (not V1).

**Wiring.** Motor cables shielded; switch cables in separate, twisted pairs; both in the cable chains on the rear side of the moving groups; tubing on the front side (`03_…` §7).

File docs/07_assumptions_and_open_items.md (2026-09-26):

<!-- GENERATED from docs/src/07_assumptions_and_open_items.md by cad/render_docs.py - edit the source, not this file -->
# Assumptions, open decisions and items NOT to finalise yet

## Assumptions made in this iteration

1. Coordinate frame: origin at the optical axis on the stage-insert top; the plate is centred on the axis at the "reference stage position" with A1 at rear-left.
2. Stage top is 200 mm above the table. **Placeholder** (M1). The frame height scales with it.
3. The IX73 body is centred on the optical axis in X. The body front face is at y = −235 mm. The pillar and condenser arm are ±45 mm wide. The condenser is a conservative Ø80 × 70 mm cylinder (`COND_PROFILE`; the real IX-ULWCD front is probably narrower). The frame is the 1-deck configuration, 656 mm high (`IX73_DECKS`; a 2-deck IX73P2F is about 721 mm, unconfirmed). **All placeholders** (M5–M9). No official IX73, condenser or motorised-stage drawing could be retrieved.
4. Condenser working distances are the manufacturer values (27/45/73 mm), measured from the well-bottom plane. The real front-lens height at the focus used may differ by a few mm (M8).
5. **V1 plate: Corning 7007 only** (U-bottom ULA, rim Ø6.86, depth 11.30), with no lid during picking. Targets within 0.5 mm of the well-bottom centre. Other plates are experimental.
6. Capillary: OD 1.0 / ID 0.6 / L 40, gripped 10 mm, 30 mm exposed. Tip stand-off 0.3 mm above the well bottom (model value; the process value is set experimentally).
7. The IX73 stage is modelled as the manual IX3-SVR (114 × 75 mm). In W-B it is replaced by, or treated as, a motorised stage with ≥ 99 × 63 mm travel that carries only the plate. The picker never loads the stage.
8. The table has free space to the right of the microscope to about +498 mm (W-A) / +458 mm (W-B) from the optical axis, plus the pump and controller beyond.
9. Actuator envelopes are width-26 class ball-screw stages; masses are ±30 % estimates.
10. Deflections are hand estimates (aluminium, simple beams); no FEA.
11. The pump, tubing and fluid volumes do not constrain the mechanics beyond a 1/16" tubing path with ≥25 mm bend radius.

## Open decisions (owner: user)

| ID | Decision | Options | Effect |
|---|---|---|---|
| D1 | Workflow | **provisional: W-B** (stage moves wells to the axis; all picks observed) vs W-A (stage fixed, blind outside the axis) — `09_workflow_D1.md` | picker travel, motorised stage ≥ 99 × 63 mm (not IX3-SSU) |
| D2 | Condenser during picking | IX-ULWCD (buy or borrow if not present) vs tilt column back + LED ring | whether the dog-leg arm is needed |
| D3 | Angle-block set | 8° / 20° / 30° per plate format; add a 10–12° block only if test M18 requires it | angle blocks, calibration |
| D4 | Side of tower | right (default) vs left (mirror) | after M12/M13/M15 |
| D5 | Z actuator type | open-loop ball screw vs closed-loop absolute (DRS2) with brake | cost, homing strategy |
| D6 | Capillary classes to stock | S/M/L (OD 1.0/1.5/2.0) vs fewer; thin-wall 2.0 for 1 mm objects | collet inserts, syringe size |
| D8 | 48-well with OD 1.5/2.0 capillaries | 8° block (reaches under 50 % of the bottom) vs a 0° block (reaches more, blocks most transmitted light) vs no 48-well use for large objects | angle-block set |
| D9 | Capillary protection in a crash | accept capillaries as consumables (V1: the break-away mount protects only the plate) vs a compliant low-force holder stage vs torque-limited landing with contact detection | holder design, cost |
| D7 | Motorised stage for W-B | Märzhäuser SCAN IM 120 × 80 class or equivalent (IX3-SSU 76 × 52 is too small) | cost, controller integration |

## Items that should NOT be finalised yet

Freeze gate: nothing below is frozen before the 10 items M1, M3, M4, M6, M7, M8, M10, M15, M19, M23 are measured and entered in `cad/params.py`.

- Actuator part numbers, strokes rounded to catalogue steps, motor frame lengths.
- Bracket geometry, fasteners, dowel positions, machining tolerances and drawings.
- Frame section sizes (80 × 80 posts/beam, 40 × 80 X support) beyond the envelope level. They need the real height (M1) and a stiffness check.
- Dog-leg arm length (120 mm in W-B, 180 mm in W-A) and thickness (12 × 12 mm). Both depend on the condenser diameter and height (M6–M8).
- Holder design (collet size, port type, kinematic mount). No commercial holder was found that positively grips OD 1.0/1.5/2.0 with a side port; the lead candidate is a custom body with ER8 collets (P10). Its nut may exceed the Ø10 mm holder envelope used in the analysis (unverified). If so, re-run `analysis.py` with the larger `HOLDER_D`.
- Budget: industrial stages on all three axes are estimated at roughly JPY 250–350k for the picker (parts research, unverified); a cheaper integrated Y stage keeps it near JPY 200k.
- IX-ULWCD availability (P09): one excerpt reports it as not available in some regions. Confirm with Evident Japan first.
- Base-plate hole pattern (M16).
- Tubing type, bore and length (pump choice M17, dead volume).
- Cable chain sizes, connector types, controller board, PSU rating.
- Safe-Z value, keep-out zone radius and approach speeds (process tests).
- Any change to the IX73 (none planned).

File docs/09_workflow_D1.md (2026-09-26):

<!-- GENERATED from docs/src/09_workflow_D1.md by cad/render_docs.py - edit the source, not this file -->
# D1: which workflow? Stage fixed (W-A) vs stage moves wells to the axis (W-B)

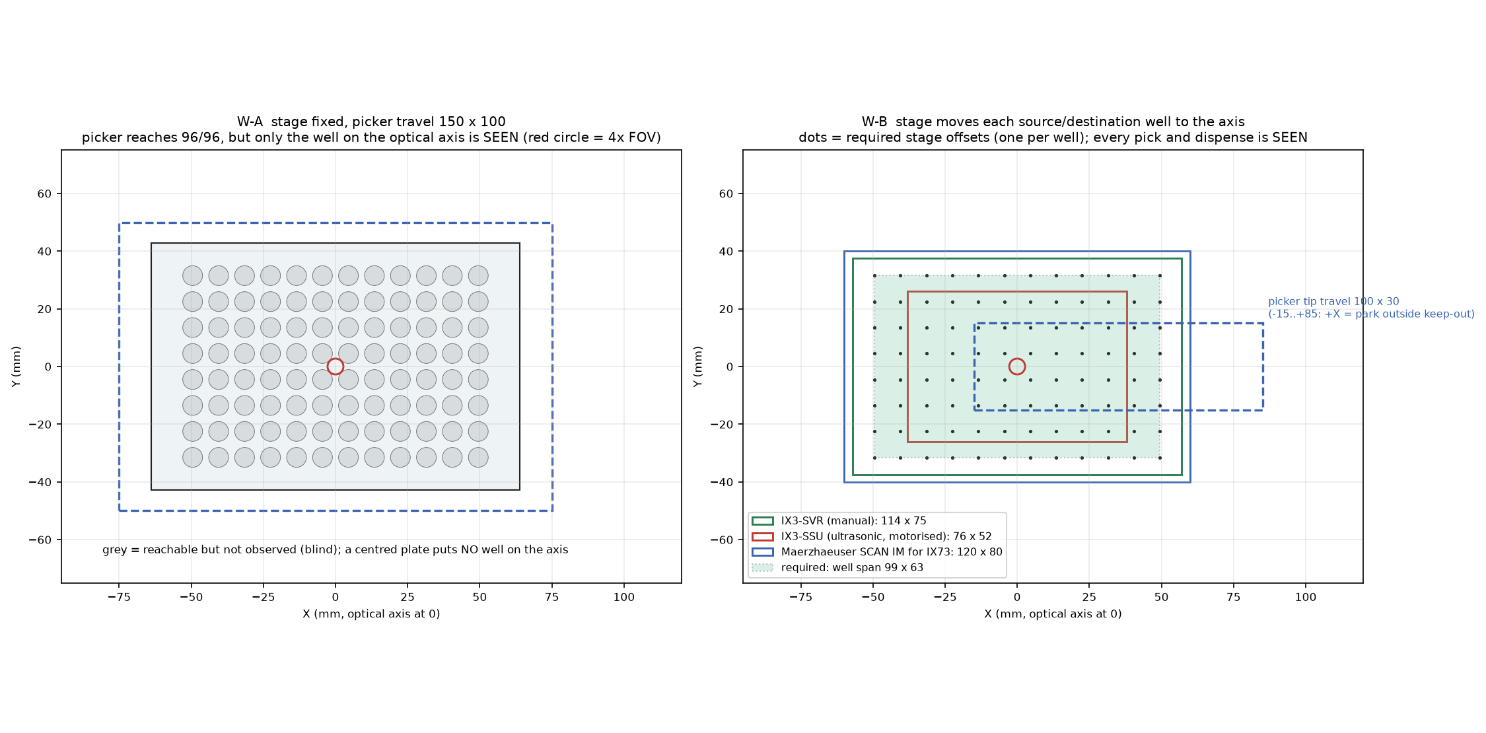
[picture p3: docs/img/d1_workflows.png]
D1 workflows


## Conclusion

If the requirement is **"pick from any of the 96 wells while watching it through the IX73"**, then **W-B is the baseline**. The IX73 stage brings the source well to the optical axis, the picker picks at the axis, and the stage then brings the destination well to the axis for an observed dispense. W-A (stage fixed, picker reaches every well) can *reach* all 96 wells but can *see* only the well on the optical axis. It observes 1 well per stage setting, and none at all with a centred plate. W-A stays valid only if the non-axis wells are served blind or by a separate overview camera.

This is a provisional choice. **Nothing is frozen until the 10 freeze-gate items (M1, M3, M4, M6, M7, M8, M10, M15, M19, M23) are measured** (see "Freeze gate" below).

## V1 scope and acceptance (issue #10)

V1 is frozen to **one plate SKU: Corning 7007** (96-well, round U-bottom, without lid during picking), with the 8° head (R08). All 96-well geometry in the model (rim Ø, depth, plate height, well-bottom height, safe-Z) comes from this SKU's profile in `params.PLATE_PROFILES`. Other plates (48-well (Corning 3548), 24-well (Corning 3524), 12-well (Corning 3513), 6-well (Corning 3516)) are **experimental** and outside V1 acceptance.

**Target location.** In a U-bottom well the object settles near the bottom centre. V1 accepts a target anywhere within **0.5 mm of the well-bottom centre**, in any direction. The binding direction is towards the far (+X) wall, where the leaning shaft is closest to the rim. For each capillary class the largest offset that still keeps the 0.5 mm rim margin is:

| Capillary class | Allowed target radius | Required | Pass |
|---|---|---|---|
| S (OD 1.0) | 0.88 mm | 0.5 mm | yes |
| M (OD 1.5) | 0.63 mm | 0.5 mm | yes |
| L (OD 2.0) | 0.37 mm | 0.5 mm | **no** |

A class that fails (allowed radius below 0.5 mm) can still pick objects that sit close to the centre, but the operator must reject off-centre targets for it; this is a known V1 limitation, not a hidden one. The measured plate lot (M19) replaces the drawing values.

## Why (numbers from the same CAD and analysis)

| | W-A stage fixed | W-B stage moves wells to the axis |
|---|---|---|
| Wells observed while picking | **1** / 96 per stage setting (4× FOV ≈ 5.5 mm) | **96** / 96 with IX3-SVR or SCAN IM |
| Dispense | blind, anywhere the picker reaches | observed, same plate (stage brings the destination to the axis) |
| Picker tip travel X × Y × Z | 150 × 100 × 50 mm | 100 × 30 × 50 mm (X -15…+85: +X is the park / capillary-change retreat) |
| Dog-leg arm / thin section under the condenser | 180 / 120 mm | **120 / 60 mm** (shorter, stiffer) |
| Tower axis from optical axis | +408 mm | +368 mm |
| Clearance sweep, R08 head, IX-ULWCD: pick / safe-Z | 96/96, 96/96 | 96/96, 96/96 (plate and stage translated for each well) |
| Stage-travel corners (stage moves with tip at safe-Z) | – | 9/9 clear |
| Min clearance at safe-Z (PH condenser) | 4.83 mm | 4.83 mm |
| Needs a motorised IX73 stage for automation | no | **yes, with ≥ 99 × 63 mm travel** |
| Extra hardware for observation | an overview camera for the non-axis wells | none |

**Stage requirement for W-B.** The plate's well span is 99 × 63 mm, so the stage must shift the plate by at least ±49.5 × ±31.5 mm:

| Stage | Travel (mm) | Motorised | Wells it can bring to the axis |
|---|---|---|---|
| IX3-SVR (manual, S02) | 114 × 75 | no | 96/96 (operator moves it: semi-automatic only) |
| IX3-SSU (Evident ultrasonic, S01) | 76 × 52 | yes | **48/96: insufficient** |
| Märzhäuser SCAN IM for IX73 (S15) | 120 × 80 | yes | 96/96 |

Evident's own ultrasonic IX3-SSU stage **cannot** bring the outer columns and rows to the axis. A W-B automation therefore needs a third-party (or other Evident) motorised stage in the 120 × 80 mm class, such as the Märzhäuser SCAN IM (2 mm pitch ball screw, per S15), or a semi-automatic mode on the manual IX3-SVR.

## Consequences of choosing W-B

1. **The picker becomes a local manipulator.** Its travel falls to 100 × 30 × 50 mm, and the arm shortens from 180 to 120 mm. The frame, the Y beam and the X cantilever all get smaller, and moving mass drops, mostly on Y. The dog-leg under the IX-ULWCD is still needed, because the pick still happens on the optical axis.
2. **Plate and stage load.** The picker never touches the stage. The motorised stage carries only the plate, well within its rating (IX3-SVR: max 1000 g, S02; check the chosen motorised stage).
3. **Sequence.** Stage: source well → axis. Z: land at about 10 µm/s and pick. Z: rise to safe-Z (19.35 mm). Stage: destination well → axis. Z: land and expel. Z: safe-Z. **The stage moves only with the tip inside the safe-Z corridor** (19.35–22.18 mm for the V1 head, `03_architecture.md` §5); the sweep confirms this is clear at all stage-travel corners. Moving it with the tip at pick height drags the capillary through the plate.
4. **Calibration** simplifies. The pick point is always the optical axis, so image → picker mapping needs only a local 3-point calibration around the axis (SpheroidPicker method, S28). Well positions come from the stage coordinates.
5. **Destination on another plate.** Two plates do not fit within the stage travel. Transfers between plates need either a plate change, or a hybrid (W-C, not modelled) where the picker carries the object at safe-Z to a fixed destination station beside the stage. W-C brings back W-A's long X travel for that one move.
6. **Throughput.** Each transfer adds two stage moves (about 1–2 s each at typical 20–50 mm/s stage speeds; to be confirmed for the chosen stage). The landings take longer. At 10 µm/s, a 50 µm slow zone costs 5 s per landing, or about 10 s per transfer. The SpheroidPicker also dwells 7 s before its pick pulse (S28). One transfer therefore takes roughly 20–30 s, which is acceptable for spheroid picking. The landings, not the stage, set the pace.

## When W-A is still the better choice

- There is no budget or space for a motorised stage, the source objects sit only in a few wells placed near the axis, and destinations can be served blind.
- A separate overview camera can image the whole plate from above (off-axis, outside the condenser keep-out), giving target coordinates for blind picking. That trades the IX73's optical quality at the pick for coverage.

## Freeze gate

The following must be measured and entered in `cad/params.py` before any part number or bracket is frozen. The model, the sweep and these documents then re-render automatically (`python tools/build_all.py`).

| Measurement | Decides |
|---|---|
| M1 stage-top height above table | frame height |
| M3 stage outline, clips; M4 stage centre vs axis | clearance to the moving plate (W-B) |
| M6 condenser model and diameter; M7 carrier arm; M8 real condenser front height | the thin-arm length, and every clearance currently at ~5 mm |
| M10 tilted-column envelope | fallback without condenser |
| M15 free table space right of the IX73 | tower placement |
| M19 V1 plate lot (Corning 7007): rim Ø, depth, height, A1 position | V1 acceptance, safe-Z lower bound |
| M23 head height above the collet nose (V1 holder, tubing clipped) | safe-Z corridor upper bound, condenser margin |
| (W-B) choice and envelope of the motorised stage (SCANplus IM dimension sheet S37 not yet retrieved) | stage travel ≥ 99 × 63, frame height above the insert, clearance to the tower |

W-B also needs the stage travel centre within the centring allowance of `03_architecture.md` §5b (M4).

The clearances of 4.83–5 mm reported by the model involve placeholder condenser geometry (a conservative Ø80 cylinder, `COND_PROFILE`) and placeholder IX73 placement. **They are provisional and are not design evidence yet.** No official IX73 or condenser drawing could be retrieved (source manifest S05, S06, S37).

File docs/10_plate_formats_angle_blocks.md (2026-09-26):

<!-- GENERATED from docs/src/10_plate_formats_angle_blocks.md by cad/render_docs.py - edit the source, not this file -->
# Plate formats and exchangeable angle blocks

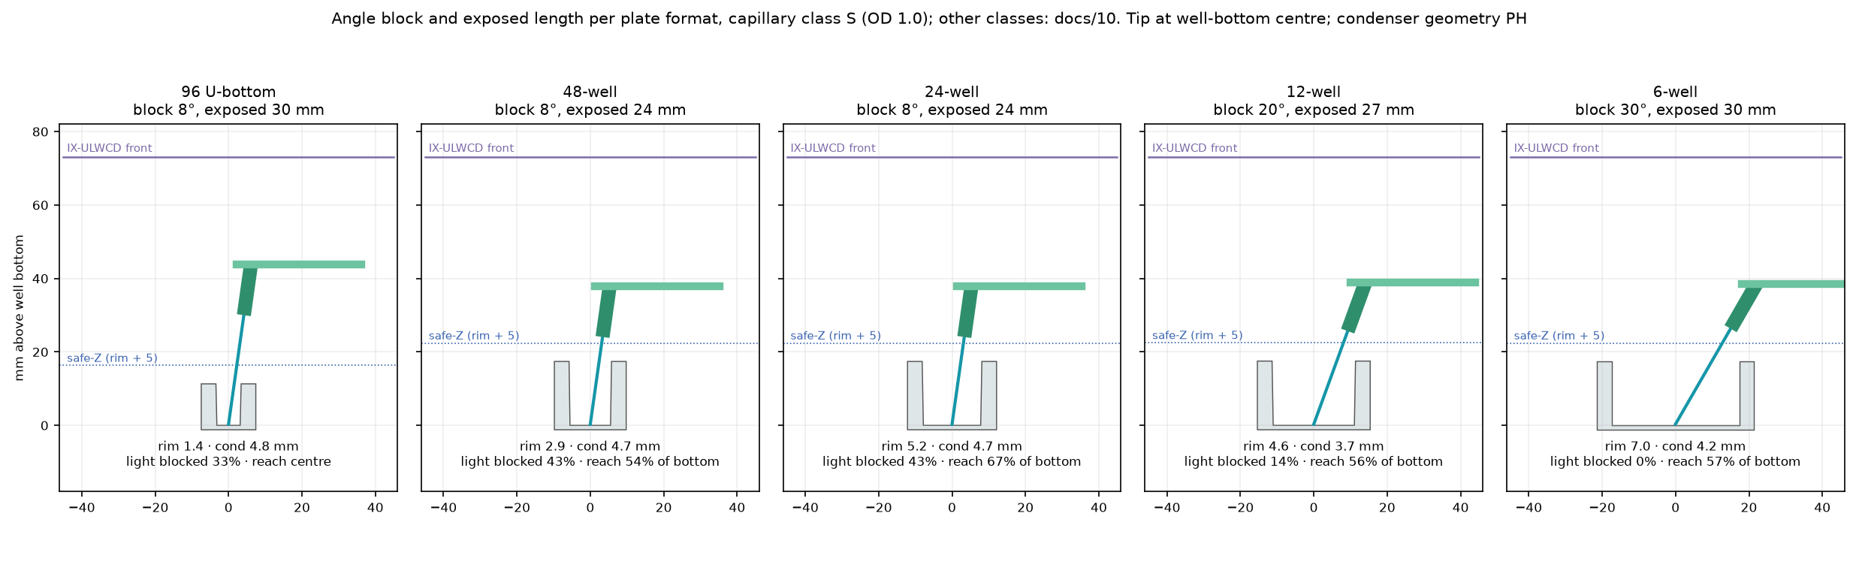
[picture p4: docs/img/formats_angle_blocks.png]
formats


## Conclusion

**Scope.** Only the **Corning 7007** 96-well U-bottom plate with the 8° block is V1. The 8° head is designed for that SKU: other 96-well plates have different rim diameters and depths and must be re-checked before use. Everything else on this page (48-well (Corning 3548), 24-well (Corning 3524), 12-well (Corning 3513), 6-well (Corning 3516)) is **experimental**: kept in the model to show that the frame can grow, but not part of V1 acceptance or ordering. Plate heights of the experimental plates are not confirmed (`MULTIWELL_HEIGHT_EXTRA`, placeholder).

A single fixed capillary angle serves the 96-well plate well but not the larger wells. The holder therefore takes **exchangeable angle blocks (8° / 20° / 30°)**. The block sits in the **holder seat at the tip end of the arm**, not at the kinematic mount on the Z carriage, so it tilts only the holder and capillary. For each plate format and capillary class, the collet's depth stop sets the **exposed capillary length**. Each block is a fixed, pre-designed geometry, which is more repeatable than a continuous tilt. A block change only needs a 3-point image re-calibration and that plate's soft limits.

## Recommended setting per plate format and capillary class

Computed by `analysis.format_angle_matrix()`. A setting is accepted when all of the following hold:

- rim clearance ≥ 0.5 mm (well geometry is manufacturer data);
- holder over plate material ≥ 2 mm;
- a positive safe-Z corridor: the head top (arm plus tubing) stays ≥ 2 mm under the condenser front with the tip at that plate's corridor lower bound (the condenser is still a placeholder);
- for flat-bottom wells, the tip can reach ≥ 50 % of the bottom area.

Among the settings that pass, the one that blocks the least transmitted light (holder plus arm, ray test at NA 0.3) is chosen. Ties go to the larger reachable area, then the longer exposed length.

| Plate | Capillary class | Angle block | Exposed length | Rim clearance | Head under condenser at safe-Z | Reachable bottom | Light blocked (NA 0.3) | Note |
|---|---|---|---|---|---|---|---|---|
| 96 U-bottom | S (OD 1.0) | 8° | 30 mm | 1.38 mm | 4.8 mm | centre (U-bottom) | 33% |  |
| 96 U-bottom | M (OD 1.5) | 8° | 30 mm | 1.13 mm | 4.8 mm | centre (U-bottom) | 33% |  |
| 96 U-bottom | L (OD 2.0) | 8° | 30 mm | 0.87 mm | 4.8 mm | centre (U-bottom) | 33% |  |
| 48-well | S (OD 1.0) | 8° | 24 mm | 2.87 mm | 4.7 mm | 54% | 43% |  |
| 48-well | M (OD 1.5) | 8° | 24 mm | 2.62 mm | 4.7 mm | 48% | 43% | reach 48% < 50%; a 0° block would reach 67% but blocks 62% of the light (D8) |
| 48-well | L (OD 2.0) | 8° | 24 mm | 2.37 mm | 4.7 mm | 42% | 43% | reach 42% < 50%; a 0° block would reach 60% but blocks 62% of the light (D8) |
| 24-well | S (OD 1.0) | 8° | 24 mm | 5.22 mm | 4.7 mm | 67% | 43% |  |
| 24-well | M (OD 1.5) | 8° | 24 mm | 4.97 mm | 4.7 mm | 62% | 43% |  |
| 24-well | L (OD 2.0) | 8° | 24 mm | 4.72 mm | 4.7 mm | 57% | 43% |  |
| 12-well | S (OD 1.0) | 20° | 27 mm | 4.57 mm | 3.7 mm | 56% | 14% |  |
| 12-well | M (OD 1.5) | 20° | 27 mm | 4.33 mm | 3.7 mm | 52% | 14% |  |
| 12-well | L (OD 2.0) | 8° | 24 mm | 7.94 mm | 4.6 mm | 69% | 43% |  |
| 6-well | S (OD 1.0) | 30° | 30 mm | 6.98 mm | 4.2 mm | 57% | 0% |  |
| 6-well | M (OD 1.5) | 30° | 30 mm | 6.76 mm | 4.2 mm | 55% | 0% |  |
| 6-well | L (OD 2.0) | 30° | 30 mm | 6.55 mm | 4.2 mm | 53% | 0% |  |

Full matrix: `generated_analysis_tables.md` §1c.

## What the matrix shows

1. **Well depth, not diameter, drives the condenser margin.** The 48/24/12/6-well plates are about 17.4 mm deep, against 11.3 mm for the 96-well. Retracting to safe-Z (rim + 5 mm) therefore lifts the head about 6 mm higher under the condenser. A shorter exposed length or a steeper block restores the margin.
2. **Head height above the nose is the most sensitive dimension.** It is defined once, as the vertical distance from the collet nose to the highest point of the head (holder, arm and tubing), and measured as M23 (`HEAD_TOP_FROM_NOSE_MEAS`). The model uses 22.2 mm for the V1 head (holder axial length 14 mm, APX). Every recommended setting keeps at least 2 mm under the condenser only if this height is no more than about **22.6 mm**. An ER8-collet holder with nut, depth stop and seal is likely 20–25 mm long (P10, unverified), so M23 is a **freeze-gate item**. The exported CAD heads are checked against the same formula (`generated_analysis_tables.md` §5d). Mitigations:
   - shorter exposed length (24 mm);
   - a holder that passes *through* the arm, so its top is the head top;
   - the tilted-back illumination option.
3. **Steeper blocks trade light for reach.** At 30° the head casts no shadow at NA 0.3, but a tilted shaft cannot follow objects near the far (+X) wall. That is why the reachable bottom area is an acceptance criterion.
4. **Stand-off must account for the tilted tip.** For a square-cut tip, the lowest edge lies r·sin θ below the tip axis. The tip-axis height tz is therefore raised so that the edge stays ≥ 0.1 mm above the bottom: 0.47 mm for OD 1.5 at 30°, 0.60 mm for OD 2.0. The firmware Z floor must be set per plate × block × capillary class from the *measured* bottom height, never below it.
5. **Some combinations fall short.** The 48-well with OD 1.5/2.0 reaches under 50 % of the bottom at 8°. A 0° block would reach more but blocks most of the light. That choice is left open as D8.
6. **45° is not needed.** In the 6-well the shaft almost touches the rim and the holder nose runs about 0.6 mm above the plate material. In smaller wells the rim blocks it outright.

## Mechanical design intent for the blocks

- The block sits between the arm tip and the holder seat, with two dowels and one clamp screw. Each block carries an engraved angle.
- Changing the block moves the tip relative to the arm by several mm: 44·(cos 8° − cos 30°) ≈ 5.5 mm in height, plus the change in exposed length. Soft limits, the Z floor and the image calibration are therefore stored **per plate × block × capillary class**.
- W-B only: the dog-leg arm and all other parts are unchanged, and the Y/X travel does not depend on the angle.

## Data status

- Plate dimensions are Corning dimension-sheet values read from search excerpts (S13, S16). The 6-well gives a single diameter (34.8 mm), and the 24-well pitch (19.3 mm) is only weakly confirmed.
- Condenser clearance uses the placeholder condenser geometry and must be recomputed after M6 and M8. It also depends one-for-one on the head height above the nose (M23, see 2).

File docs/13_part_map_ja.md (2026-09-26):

<!-- GENERATED by docs/parts/build_partmap.py from docs/parts/part_map.py - edit part_map.py -->
# 部品の対応表(どこの部品が何に当たるか)

図の番号 1–27 が、実物の部品、CAD のパーツ名、部品候補リストの番号(P01–P42)、組立工程、関係する実測項目をつなぎます。W-B(ステージが動く)構成、8° ヘッド、IX-ULWCD の状態で描いています。番号はこの表と図で共通です。

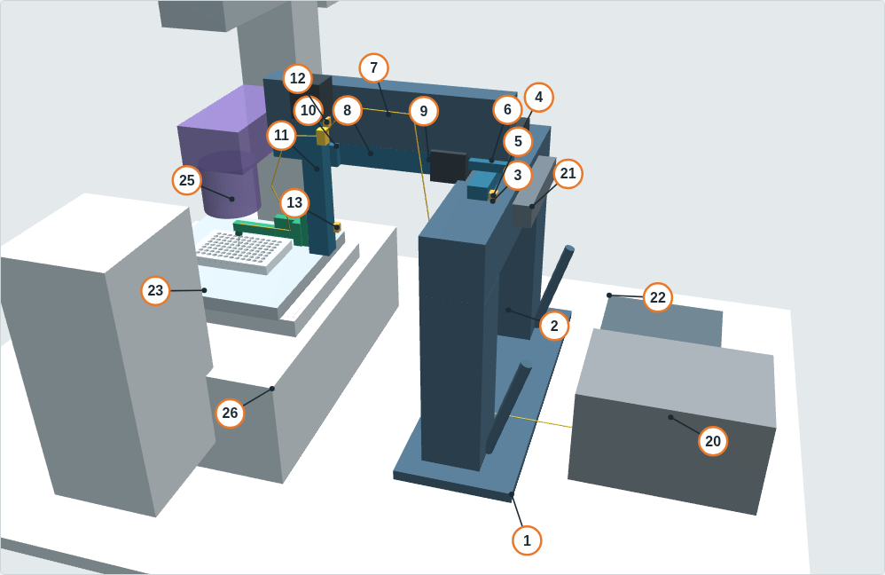
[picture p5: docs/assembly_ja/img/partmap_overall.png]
全体図(番号付き)


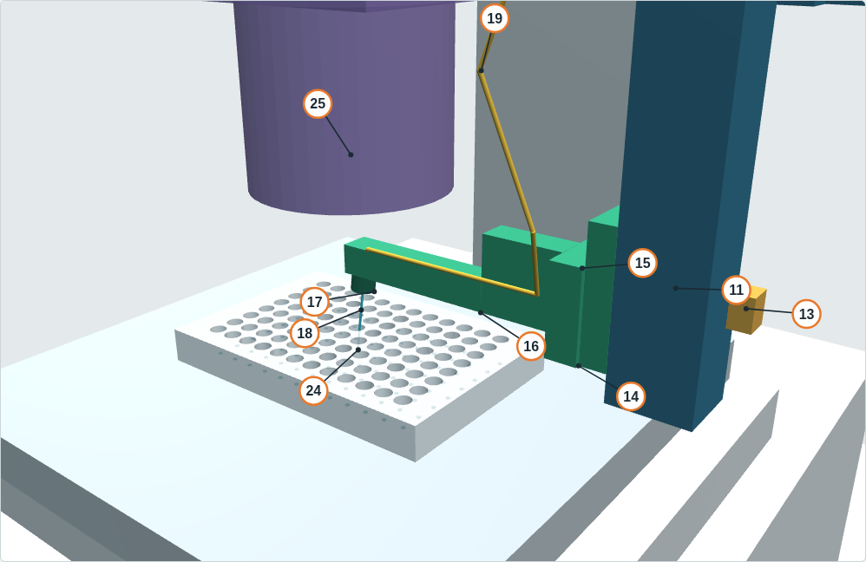
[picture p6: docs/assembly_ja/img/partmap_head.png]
ヘッド周りの拡大図(番号付き)


全体図では架台、3 軸、電装、顕微鏡側に番号を付け、ヘッド周り(14–19、24)は拡大図に付けています。20 と 22 は定盤の上、架台の外側に置く箱(ポンプと制御箱)です。

## 対応表

区分は、製作 = 図面を起こして作る、購入 = 市販品を買う、既存 = 研究室にあるものを使う、顕微鏡 = 顕微鏡側の機器(ピッカーとしては作らない)です。

| 番号 | 部品 | 役割 | 区分 | 部品候補(P) | 組立 | 関係する実測など | CAD のパーツ名 |
|---|---|---|---|---|---|---|---|
| 1 | ベース板 | 架台全体を定盤に固定する土台。長穴で位置と向きを調整する | 製作 | P16, P37 | 工程 1 | M15, M16 | `base_plate` |
| 2 | 支柱と筋交い | Y 梁を必要な高さに支える 2 本の柱 | 購入 | P17, P20 | 工程 2 | M1 | `post_*, post_brace_*` |
| 3 | Y 梁 | 両端で支えた固定梁。Y ステージを載せる | 購入 | P18 | 工程 3 | M1 | `y_beam` |
| 4 | Y ステージ | 先端を Y(奥行き)方向に動かす軸 | 購入 | P03, P04, P06 | 工程 4 | モーメント(03 §5b) | `Y_actuator_body, Y_motor` |
| 5 | Y 原点スイッチ | Y の原点(手前側端) | 購入 | P30 | 工程 4 | — | `Y_home_switch` |
| 6 | Y キャリッジ | Y ステージの可動台。X 支持梁を載せる | 製作 | P15 | 工程 5 | — | `Y_carriage` |
| 7 | X 支持梁 | Y キャリッジから光軸側へ張り出す片持ち梁 | 購入 | P19 | 工程 5 | M7 | `X_support_beam` |
| 8 | X ステージ | 先端を X(左右)方向に動かす軸。待避位置もこの軸 | 購入 | P02, P04, P06 | 工程 5 | — | `X_actuator_body, X_motor` |
| 9 | X 原点スイッチ | X の原点(外側端) | 購入 | P30 | 工程 5 | — | `X_home_switch` |
| 10 | X キャリッジブラケット | X の可動台に Z ステージを鉛直に固定する | 製作 | P15 | 工程 6 | — | `X_carriage_bracket` |
| 11 | Z ステージ | 先端を上下させる軸。着地精度と停電時に落ちないことが要 | 購入 | P01, P05, P06 | 工程 6 | — | `Z_actuator_body, Z_motor` |
| 12 | Z 上端リミットスイッチ | 行き過ぎ防止のみ。安全な位置ではない | 購入 | P30 | 工程 6 | — | `Z_home_switch_top` |
| 13 | Z 基準スイッチ | Z の原点。ヘッド最上部がコンデンサ下端より余裕を残す高さ(1 個だけ) | 購入 | P42 | 工程 6 | M8, M23 | `Z_reference_switch` |
| 14 | Z キャリッジ | Z ステージの可動台。マウントとアームを付ける | 製作 | P15 | 工程 6 | — | `Z_carriage` |
| 15 | キネマティックマウント | 衝突で外れ、同じ位置に戻る(力の制限ではない) | 購入 | P12 | 工程 7 | — | `breakaway_kinematic_mount` |
| 16 | ドッグレッグアーム | コンデンサの下へ差し込む薄い腕。Z 本体を光軸の外に置く | 製作 | P14 | 工程 7 | M6, M7, M8 | `arm_deep, arm_thin` |
| 17 | キャピラリホルダーと角度ブロック | コレットでキャピラリをつかみ、ブロックで傾き(8°/20°/30°)を決める | 製作 | P10, P11, P13 | 工程 7 | M23 | `capillary_holder_collet` |
| 18 | ガラスキャピラリ | 対象物を吸う先端。対象の大きさで太さを選ぶ(消耗品) | 購入 | P21, P22, P23, P24 | 工程 10 | — | `glass_capillary_OD1.0` |
| 19 | チューブとクランプ | ポンプからキャピラリまでの液の経路。サービスループで動きを逃がす | 購入 | P25, P26 | 工程 9 | — | `tubing_clamp_Zbody, tubing_fixed_clamp, tubing_head_*, tubing_loopXY_*, tubing_loopZ_*, tubing_to_pump_*` |
| 20 | シリンジポンプ | 吸引と吐出。架台には載せない | 既存 | P38, P40, P27, P41 | 工程 9 | M17 | `syringe_pump_existing` |
| 21 | ケーブルチェーン | モーターとスイッチの配線を可動部の奥側で逃がす | 購入 | P34, P35 | 工程 8 | — | `X_cable_chain, Y_cable_chain` |
| 22 | 制御箱 | コントローラ、ドライバ、24 V 電源、非常停止回路 | 購入 | P28, P29, P31, P32, P33, P36 | 工程 8 | — | `motion_controller_24V` |
| 23 | 電動 XY ステージとプレートホルダー | W-B でウェルを光軸へ運ぶ(ピッカーは触れない) | 顕微鏡 | P07, P08, P39 | — | M3, M4 | `ix73_stage` |
| 24 | 96 穴プレート(Corning 7007) | V1 の対象プレート。蓋は外して使う | 既存 | — | — | M19 | `plate_96_SLAS` |
| 25 | コンデンサ(IX-ULWCD)と保持アーム | 透過照明。アームはこの下を通る | 顕微鏡 | P09 | — | M6, M7, M8 | `condenser_IX-ULWCD, condenser_carrier_arm, illum_arm_to_pillar` |
| 26 | IX73 本体(外形の目安) | 位置関係を見るための仮の外形。寸法は実測で置き換える | 顕微鏡 | — | — | M1, M5, M9, M12–M14 | `ix73_body_lower, ix73_illum_pillar, ix73_lamp_house, ix73_objective_zone, ix73_obs_tube_eyepieces, ix73_stage_handle, ix73_stage_support, optical_table_patch` |
| 27 | 比較用の外形 | 別のコンデンサと、照明支柱を倒した状態。比較のためだけに表示 | 顕微鏡 | — | — | M10 | `condenser_IX2-LWUCD, condenser_IX2-MLWCD, illum_arm_tilted_back` |

## 部品候補の番号から引く

発注や見積のときに、部品候補リスト(`12_parts_candidates.md`)の番号から図の番号を引くための表です。

| 部品候補 | 分類 | 品目(候補リストの表記) | 図の番号 |
|---|---|---|---|
| P01 | Actuator | Z stage (vertical, landing axis) | 11 |
| P02 | Actuator | X stage (cantilevered, tip X) | 8 |
| P03 | Actuator | Y stage (on fixed Y beam) | 4 |
| P04 | Motor | NEMA17 stepper motors, X and Y | 4, 8 |
| P05 | Motor | NEMA17 stepper motor for Z (optional brake) | 11 |
| P06 | Mechanical | Motor brackets + shaft couplings | 4, 8, 11 |
| P07 | Microscope | Motorised XY stage for IX73 (W-B) | 23 |
| P08 | Microscope | Stage controller + joystick | 23 |
| P09 | Microscope | IX-ULWCD long-working-distance condenser (if not owned) | 25 |
| P10 | Capillary holder | Collet capillary holder (custom) with inserts OD 1.0/1.5/2.0 | 17 |
| P11 | Capillary holder | Commercial pipette holder with side port (reference/spare, 1.0-2.0 mm) | 17 |
| P12 | Mechanical | Kinematic magnetic break-away mount (Z carriage <-> arm) | 15 |
| P13 | Mechanical | Exchangeable angle blocks 8 / 20 / 30 deg | 17 |
| P14 | Mechanical | Dog-leg arm (115 mm, 12x12 thin section) | 16 |
| P15 | Mechanical | Carriage brackets (X carriage->Z body, Y carriage->X beam), tubing clamps | 6, 10, 14 |
| P16 | Frame | Base plate, 15 mm aluminium, slotted for table grid | 1 |
| P17 | Frame | Posts, aluminium extrusion 80x80 | 2 |
| P18 | Frame | Y beam, aluminium extrusion 80x80, ~390 mm | 3 |
| P19 | Frame | X support beam, aluminium extrusion 40x80 (cantilever) | 7 |
| P20 | Frame | Extrusion fasteners: brackets, post-assembly nuts, diagonal braces, jack screw | 2 |
| P21 | Consumable | Glass capillaries class S: OD 1.0 / ID 0.58 | 18 |
| P22 | Consumable | Glass capillaries class M: OD 1.5 / ID 0.84-0.86 | 18 |
| P23 | Consumable | Glass capillaries class L: OD 2.0 / ID 1.12 | 18 |
| P24 | Consumable | Glass capillaries class L': thin wall OD 2.00 / ID 1.56 | 18 |
| P25 | Fluidics | PTFE/FEP tubing 1/16" OD | 19 |
| P26 | Fluidics | Fittings 1/4-28 flat-bottom for 1/16" tubing (+ferrules, unions) | 19 |
| P27 | Fluidics | Pump interface: Luer to 1/4-28 adapter (Harvard) / direct 1/4-28 (Tecan Cavro) | 20 |
| P28 | Electronics | Motion controller (G-code / serial, >=3 axes, >=6 NC inputs) | 22 |
| P29 | Electronics | TMC5160 stepper drivers (only if controller has sockets) | 22 |
| P30 | Electronics | Home switches, NC / fail-safe (X out, Y front, Z top) + optional far limits | 5, 9, 12 |
| P31 | Electronics | 24 V DC PSU (~150 W) | 22 |
| P32 | Safety | E-stop push button (2NC) | 22 |
| P33 | Safety | Safety relay / contactor cutting motor 24 V (logic stays on) | 22 |
| P34 | Wiring | Cable chains (X on Y group; Y on frame) | 21 |
| P35 | Wiring | Motor (shielded) and switch (twisted pair) cables, chain-rated | 21 |
| P36 | Electronics | Enclosure, DIN rail, fuses, terminal blocks, USB cable | 22 |
| P37 | Frame | Table mounting hardware | 1 |
| P38 | Fluidics | Syringe pump (existing Harvard or Tecan) - no purchase | 20 |
| P39 | Microscope | SBS plate insert / holder for the motorised XY stage | 23 |
| P40 | Fluidics | Syringe for the existing pump (gas-tight) | 20 |
| P41 | Fluidics | Optional pinch/NC valve and pressure tee on the fixed side | 20 |
| P42 | Electronics | Z reference switch (below the condenser) | 13 |

## この表の保ち方

対応は `docs/parts/part_map.py` の一か所だけに書いてあります。組立工程の割り当てもここにあり、ビューアの工程図もここから作ります。`python tools/build_all.py --check` と CI のテストは、W-B の CAD パーツがどれか一つの番号にだけ入っていること、部品候補 P01–P42 がすべてどこかの番号に入っていることを確かめます。部品を増やしたら、`part_map.py` に一行足して再生成してください。

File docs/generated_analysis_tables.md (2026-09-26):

<!-- generated by cad/analysis.py - do not edit by hand -->
# Generated analysis tables

## 1. Well-wall access (Corning 7007 U-bottom: top Ø6.86, depth 11.30; capillary OD 1.0)

| angle from vertical | rim clearance, tip at bottom centre (mm) | max centred reach below rim (mm) | bottom centre reachable | bottom reachable anywhere |
|---|---|---|---|---|
| 0° | 2.93 | 11.3 | yes | yes |
| 5° | 1.97 | 11.3 | yes | yes |
| 8° | 1.38 | 11.3 | yes | yes |
| 10° | 0.98 | 11.3 | yes | yes |
| 12° | 0.58 | 11.3 | yes | yes |
| 14° | 0.17 | 11.3 | yes | yes |
| 15° | -0.04 | 10.9 | NO | yes |
| 20° | -1.11 | 8.0 | NO | yes |
| 30° | -3.50 | 4.9 | NO | NO |
| 45° | -8.28 | 2.7 | NO | NO |

Maximum angle for reaching the bottom centre: **14.8°** (tip 0.3 mm above bottom, no margin).

### 1b. Capillary set vs well access (object size 100 um - 1 mm)

| class | OD | ID | max angle for bottom centre | rim clearance at 8° (mm) | catalogue part | data |
|---|---|---|---|---|---|---|
| S  (100-300 um) | 1.0 | 0.58 | 14.8° | 1.38 | WPI 1B100-4 (or tip cut/pulled to ID 0.2-0.35) | MFR |
| M  (300-600 um) | 1.5 | 0.84 | 13.6° | 1.13 | WPI 1B150-4 / Sutter B150-86 (ID 0.86) | MFR |
| L  (600-800 um) | 2.0 | 1.12 | 12.3° | 0.87 | WPI 1B200-4 - only 1.12x a 1 mm object | MFR |
| L' (800-1000 um) | 2.0 | 1.56 | 12.3° | 0.87 | WPI thin-wall 2.00/1.56 (no filament) | MFR |

### 1c. Plate formats x capillary angle (OD 1.0, exposed 30 mm, IX-ULWCD)

OK = rim >= 0.5 mm, holder over plate and head top (arm + tubing) under the condenser at safe-Z >= 2.0 mm, flat wells reachable bottom area >= 50%. Tip axis height tz keeps the lowest edge of the tilted tip >= 0.1 mm above the bottom.

| plate | angle | tz (mm) | rim clearance | holder over plate | condenser at safe-Z | reachable bottom | light blocked (NA 0.3) | OK |
|---|---|---|---|---|---|---|---|---|
| 96 U-bottom (Corning 7007) | 0° | 0.30 | 2.93 | 19.0 | 4.4 | centre (U) | 47% | yes |
| 96 U-bottom (Corning 7007) | 8° | 0.30 | 1.38 | 18.0 | 4.8 | centre (U) | 33% | yes |
| 96 U-bottom (Corning 7007) | 20° | 0.30 | -1.11 | 15.5 | 7.1 | centre (U) | 12% | no |
| 96 U-bottom (Corning 7007) | 30° | 0.35 | -3.47 | 12.5 | 10.3 | centre (U) | 0% | no |
| 96 U-bottom (Corning 7007) | 45° | 0.45 | -8.12 | 6.8 | 17.3 | centre (U) | 0% | no |
| 48-well (Corning 3548) | 0° | 0.30 | 5.28 | not over rim | -1.7 | 75% | 47% | no |
| 48-well (Corning 3548) | 8° | 0.30 | 2.87 | 11.9 | -1.3 | 54% | 33% | no |
| 48-well (Corning 3548) | 20° | 0.30 | -0.98 | 9.4 | 1.0 | 19% | 12% | no |
| 48-well (Corning 3548) | 30° | 0.35 | -4.64 | 6.4 | 4.2 | 0% | 0% | no |
| 48-well (Corning 3548) | 45° | 0.45 | -11.87 | 0.7 | 11.2 | 0% | 0% | no |
| 24-well (Corning 3524) | 0° | 0.30 | 7.63 | not over rim | -1.7 | 84% | 47% | no |
| 24-well (Corning 3524) | 8° | 0.30 | 5.22 | 11.9 | -1.3 | 67% | 33% | no |
| 24-well (Corning 3524) | 20° | 0.30 | 1.37 | 9.4 | 1.0 | 40% | 12% | no |
| 24-well (Corning 3524) | 30° | 0.35 | -2.29 | 6.4 | 4.2 | 17% | 0% | no |
| 24-well (Corning 3524) | 45° | 0.45 | -9.52 | 0.7 | 11.2 | 0% | 0% | no |
| 12-well (Corning 3513) | 0° | 0.30 | 10.87 | not over rim | -1.8 | 88% | 47% | no |
| 12-well (Corning 3513) | 8° | 0.30 | 8.44 | not over rim | -1.4 | 76% | 33% | no |
| 12-well (Corning 3513) | 20° | 0.30 | 4.57 | 9.3 | 0.9 | 56% | 12% | no |
| 12-well (Corning 3513) | 30° | 0.35 | 0.89 | 6.3 | 4.1 | 37% | 0% | no |
| 12-well (Corning 3513) | 45° | 0.45 | -6.39 | 0.6 | 11.1 | 8% | 0% | no |
| 6-well (Corning 3516) | 0° | 0.30 | 16.90 | not over rim | -1.7 | 89% | 47% | no |
| 6-well (Corning 3516) | 8° | 0.30 | 14.49 | not over rim | -1.3 | 83% | 33% | no |
| 6-well (Corning 3516) | 20° | 0.30 | 10.64 | not over rim | 1.0 | 70% | 12% | no |
| 6-well (Corning 3516) | 30° | 0.35 | 6.98 | 6.4 | 4.2 | 57% | 0% | yes |
| 6-well (Corning 3516) | 45° | 0.45 | -0.25 | 0.7 | 11.2 | 34% | 0% | no |

Recommended angle block and exposed length per plate and capillary class (max nose-to-head-top = largest M23 value that keeps 2.0 mm under the condenser; model value 22.2 mm at 8°):

| plate | class | block | exposed | tz (mm) | rim | condenser at safe-Z | reachable | light blocked | max nose-to-head-top (mm) | note |
|---|---|---|---|---|---|---|---|---|---|---|
| 96 U-bottom (Corning 7007) | S (OD 1.0) | 8° | 30 mm | 0.30 | 1.38 | 4.8 | centre (U) | 33% | 25.0 |  |
| 96 U-bottom (Corning 7007) | M (OD 1.5) | 8° | 30 mm | 0.30 | 1.13 | 4.8 | centre (U) | 33% | 25.0 |  |
| 96 U-bottom (Corning 7007) | L (OD 2.0) | 8° | 30 mm | 0.30 | 0.87 | 4.8 | centre (U) | 33% | 25.0 |  |
| 48-well (Corning 3548) | S (OD 1.0) | 8° | 24 mm | 0.30 | 2.87 | 4.7 | 54% | 43% | 24.8 |  |
| 48-well (Corning 3548) | M (OD 1.5) | 8° | 24 mm | 0.30 | 2.62 | 4.7 | 48% | 43% | 24.8 | reach 48% < 50%; a 0° block would reach 67% but blocks 62% of the light (D8) |
| 48-well (Corning 3548) | L (OD 2.0) | 8° | 24 mm | 0.30 | 2.37 | 4.7 | 42% | 43% | 24.8 | reach 42% < 50%; a 0° block would reach 60% but blocks 62% of the light (D8) |
| 24-well (Corning 3524) | S (OD 1.0) | 8° | 24 mm | 0.30 | 5.22 | 4.7 | 67% | 43% | 24.8 |  |
| 24-well (Corning 3524) | M (OD 1.5) | 8° | 24 mm | 0.30 | 4.97 | 4.7 | 62% | 43% | 24.8 |  |
| 24-well (Corning 3524) | L (OD 2.0) | 8° | 24 mm | 0.30 | 4.72 | 4.7 | 57% | 43% | 24.8 |  |
| 12-well (Corning 3513) | S (OD 1.0) | 20° | 27 mm | 0.30 | 4.57 | 3.7 | 56% | 14% | 23.1 |  |
| 12-well (Corning 3513) | M (OD 1.5) | 20° | 27 mm | 0.36 | 4.33 | 3.7 | 52% | 14% | 23.1 |  |
| 12-well (Corning 3513) | L (OD 2.0) | 8° | 24 mm | 0.30 | 7.94 | 4.6 | 69% | 43% | 24.7 |  |
| 6-well (Corning 3516) | S (OD 1.0) | 30° | 30 mm | 0.35 | 6.98 | 4.2 | 57% | 0% | 22.6 |  |
| 6-well (Corning 3516) | M (OD 1.5) | 30° | 30 mm | 0.47 | 6.76 | 4.2 | 55% | 0% | 22.6 |  |
| 6-well (Corning 3516) | L (OD 2.0) | 30° | 30 mm | 0.60 | 6.55 | 4.2 | 53% | 0% | 22.6 |  |

## 2. Transmitted light blocked by the head (holder Ø10 + 12 mm arm, ray test; capillary ignored)

| angle | condenser NA used | cone radius at holder nose (mm) | holder offset (mm) | blocked fraction |
|---|---|---|---|---|
| 0° | 0.1 | 3.05 | 0.0 | 100% |
| 0° | 0.3 | 9.53 | 0.0 | 47% |
| 8° | 0.1 | 3.02 | 4.18 | 61% |
| 8° | 0.3 | 9.44 | 4.18 | 32% |
| 30° | 0.1 | 2.64 | 15.0 | 0% |
| 30° | 0.3 | 8.26 | 15.0 | 0% |
| 45° | 0.1 | 2.16 | 21.21 | 0% |
| 45° | 0.3 | 6.77 | 21.21 | 0% |

## 3. Clearance sweep (OCC min distance; moving parts vs IX73/condenser/plate/pump envelopes)

W-A poses: 96 wells at pick height and at safe-Z (plate top + 5 mm), with the picker moving to each well.
W-B poses: the IX73 stage brings each well to the optical axis (plate and stage translate), picker at the axis;
plus the IX3-SVR stage-travel corners. Both: 35-point grid over the picker's own travel at safe-Z and at top-Z.
PH = placeholder geometry is involved in every condenser/IX73 result; treat as provisional.

| workflow | head | condenser | pick OK /96 | safe-Z OK /96 | grid safe-Z OK /35 | grid top-Z OK /35 | stage corners OK | colliding obstacles (pose count) | min clearance, safe-Z (mm) |
|---|---|---|---|---|---|---|---|---|---|
| WA | R08 | IX2-LWUCD | 16 | 16 | 20 | 15 | – | condenser_IX2-LWUCD (593), condenser_carrier_arm (36) | 0.0 |
| WA | R08 | IX2-MLWCD | 18 | 16 | 20 | 20 | – | condenser_IX2-MLWCD (511) | 0.0 |
| WA | R08 | IX-ULWCD | 96 | 96 | 35 | 20 | – | condenser_IX-ULWCD (47) | 4.83 |
| WA | R08 | NONE (pillar tilted back) | 96 | 96 | 35 | 35 | – | none | 5.74 |
| WA | V00 | IX2-LWUCD | 10 | 10 | 20 | 11 | – | condenser_IX2-LWUCD (587), condenser_carrier_arm (64) | 0.0 |
| WA | V00 | IX2-MLWCD | 10 | 10 | 20 | 19 | – | condenser_IX2-MLWCD (513), condenser_carrier_arm (4) | 0.0 |
| WA | V00 | IX-ULWCD | 96 | 96 | 35 | 20 | – | condenser_IX-ULWCD (43) | 4.4 |
| WA | V00 | NONE (pillar tilted back) | 96 | 96 | 35 | 35 | – | none | 5.8 |
| WA | V20 | IX2-LWUCD | 0 | 20 | 20 | 20 | – | condenser_IX2-LWUCD (623), plate_96_SLAS (96) | 0.0 |
| WA | V20 | IX2-MLWCD | 0 | 20 | 20 | 20 | – | condenser_IX2-MLWCD (496), plate_96_SLAS (96) | 0.0 |
| WA | V20 | IX-ULWCD | 0 | 96 | 35 | 20 | – | plate_96_SLAS (96), condenser_IX-ULWCD (50) | 5.66 |
| WA | V20 | NONE (pillar tilted back) | 0 | 96 | 35 | 35 | – | plate_96_SLAS (96) | 5.66 |
| WA | V30 | IX2-LWUCD | 0 | 22 | 20 | 20 | – | condenser_IX2-LWUCD (574), plate_96_SLAS (96) | 0.0 |
| WA | V30 | IX2-MLWCD | 0 | 26 | 22 | 20 | – | condenser_IX2-MLWCD (448), plate_96_SLAS (96) | 0.0 |
| WA | V30 | IX-ULWCD | 0 | 96 | 35 | 22 | – | plate_96_SLAS (96), condenser_IX-ULWCD (44) | 5.62 |
| WA | V30 | NONE (pillar tilted back) | 0 | 96 | 35 | 35 | – | plate_96_SLAS (96) | 5.62 |
| WA | V45 | IX2-LWUCD | 0 | 26 | 22 | 20 | – | condenser_IX2-LWUCD (524), plate_96_SLAS (96) | 0.0 |
| WA | V45 | IX2-MLWCD | 0 | 36 | 23 | 20 | – | condenser_IX2-MLWCD (253), plate_96_SLAS (96) | 0.0 |
| WA | V45 | IX-ULWCD | 0 | 96 | 35 | 23 | – | plate_96_SLAS (96), condenser_IX-ULWCD (47) | 5.57 |
| WA | V45 | NONE (pillar tilted back) | 0 | 96 | 35 | 35 | – | plate_96_SLAS (96) | 5.57 |
| WB | R08 | IX2-LWUCD | 0 | 0 | 15 | 15 | 0/9 | condenser_IX2-LWUCD (709), condenser_carrier_arm (30) | 0.0 |
| WB | R08 | IX2-MLWCD | 0 | 0 | 15 | 15 | 0/9 | condenser_IX2-MLWCD (612) | 0.0 |
| WB | R08 | IX-ULWCD | 96 | 96 | 35 | 15 | 9/9 | condenser_IX-ULWCD (59) | 4.83 |
| WB | R08 | NONE (pillar tilted back) | 96 | 96 | 35 | 35 | 9/9 | none | 5.74 |
| WB | V20 | IX2-LWUCD | 0 | 0 | 17 | 15 | 0/9 | condenser_IX2-LWUCD (790), plate_96_SLAS (96) | 0.0 |
| WB | V20 | IX2-MLWCD | 0 | 0 | 20 | 15 | 0/9 | condenser_IX2-MLWCD (712), plate_96_SLAS (96) | 0.0 |
| WB | V20 | IX-ULWCD | 0 | 96 | 35 | 19 | 9/9 | plate_96_SLAS (96), condenser_IX-ULWCD (62) | 5.66 |
| WB | V20 | NONE (pillar tilted back) | 0 | 96 | 35 | 35 | 9/9 | plate_96_SLAS (96) | 5.66 |
| WB | V30 | IX2-LWUCD | 0 | 0 | 20 | 15 | 0/9 | condenser_IX2-LWUCD (783), plate_96_SLAS (96) | 0.0 |
| WB | V30 | IX2-MLWCD | 0 | 0 | 20 | 15 | 0/9 | condenser_IX2-MLWCD (706), plate_96_SLAS (96) | 0.0 |
| WB | V30 | IX-ULWCD | 0 | 96 | 35 | 20 | 9/9 | plate_96_SLAS (96), condenser_IX-ULWCD (56) | 5.62 |
| WB | V30 | NONE (pillar tilted back) | 0 | 96 | 35 | 35 | 9/9 | plate_96_SLAS (96) | 5.62 |

## 4. Workflow comparison (D1): wells that can be picked while observed through the IX73

Field of view assumed 5.5 mm at 4x (APX). W-A: plate centred on the axis.

| workflow | wells observed while picking | wells reachable by picker XY alone | picker travel X x Y x Z (mm) | arm length / thin section (mm) | tower axis x (mm) |
|---|---|---|---|---|---|
| W-A stage fixed: picker covers the plate | 1 (at a centred plate: 0) | 96 | 150 x 100 x 50 | 180 / 120 | 408 |
| W-B stage moves wells to the optical axis: picker works locally | 96 (best stage) | 32 | 100 x 30 x 50 | 120 / 60 | 368 |

W-B: wells the stage can bring to the optical axis, per stage (needs >= 99 x 63 mm travel):

| stage | travel X x Y (mm) | motorised | wells reachable on the axis |
|---|---|---|---|
| IX3-SVR (manual) | 114 x 75 | no | 96/96 |
| IX3-SSU (ultrasonic, motorised) | 76 x 52 | yes | 48/96 |
| Maerzhaeuser SCAN IM for IX73 | 120 x 80 | yes | 96/96 |

## 5. Safety, acceptance and load checks (issues #5-#8, #10)

### 5a. Safe-Z corridor per head configuration (tip height above the stage datum)

Lower = highest moving plate/stage feature + margin (stage moves only at or above it). Upper = condenser front - head top - margin. The ONE physical Z reference switch puts the tip at 'tip at ref'.

| config | scope | plate | lower | upper | width | tip at reference | feasible | >= preferred width | ref inside corridor |
|---|---|---|---|---|---|---|---|---|---|
| R08 | V1 | 96 U-bottom (Corning 7007) | 19.35 | 22.18 | 2.83 | 22.13 | yes | yes | yes |
| V20 | experimental | 12-well (Corning 3513) | 25.50 | 27.17 | 1.67 | 27.17 | yes | no | yes |
| V30 | experimental | 6-well (Corning 3516) | 25.40 | 27.59 | 2.19 | 27.59 | yes | yes | yes |
| V00 | comparison | 96 U-bottom (Corning 7007) | 19.35 | 21.75 | 2.40 | 21.70 | yes | yes | yes |
| V45 | comparison | 96 U-bottom (Corning 7007) | 19.35 | 34.64 | 15.29 | 34.59 | yes | yes | yes |

### 5b. V1 acceptance: target offset from the U-bottom centre (required <= 0.5 mm)

| capillary class | largest allowed offset towards +X (mm) | meets requirement |
|---|---|---|
| S (OD 1.0) | 0.88 | yes |
| M (OD 1.5) | 0.63 | yes |
| L (OD 2.0) | 0.37 | NO |

### 5c. Exported CAD head vs analytic head record (head top above tip, under the condenser)

| config | CAD | analytic | difference | consistent |
|---|---|---|---|---|
| R08 | 51.872 | 51.872 | +0.000 | yes |
| V20 | 46.827 | 46.827 | +0.000 | yes |
| V30 | 46.405 | 46.405 | +0.000 | yes |
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

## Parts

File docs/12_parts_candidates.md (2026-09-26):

<!-- GENERATED from docs/parts/candidates.csv by docs/parts/build_parts.py - edit the CSV -->
# Parts candidates (stage 1, NOT an order list)

Candidates for each line item of the W-B baseline, researched from web-search excerpts on 2026-09-26. Vendor pages could not be opened from the authoring environment, so **part numbers, specs, prices and lead times must be confirmed in a quotation** before ordering, and nothing is ordered before the freeze gate (M1, M3, M4, M6, M7, M8, M10, M15, M19, M23). Research notes and all URLs: `docs/parts/research_notes.md`.

| ID | Category | Item | Qty | Requirement | Candidate 1 | Candidate 2 | Key spec | Approx. price | Verified |
|---|---|---|---|---|---|---|---|---|---|
| P01 | Actuator | Z stage (vertical, landing axis) | 1 | actuator stroke >=50 mm (tip travel 50 mm; model uses 80 mm catalogue stroke); ball screw lead 1 mm; no drop unpowered; compact width; repeatability <=10 um | THK KR20 LM Guide Actuator, lead 1: KR2001A-0080-P0-01A0 (precision) or KR2001A-0080-H0-01A0 (high-accuracy); 80 mm stroke, no cover | MISUMI LX20 lead 1 (LX2001P precision grade); stroke/motor bracket code to be configured on MISUMI site | KR20: ball screw lead 1 or 6 mm, strokes 30/80/130 seen as stock PNs; grades normal/H/P. LX20: repeatability +-0.005 (high grade) / +-0.003 (precision). DRS2: repeatability +-0.01 rolled / +-0.003 ground; brake option | KR20: not found (used unit on eBay ~USD 108 + shipping); DRS2 with driver: not found | PNs verified (Oriental Motor THK listing); KR20 numeric repeatability per grade UNVERIFIED (THK accuracy table exists but values not seen) |
| P02 | Actuator | X stage (cantilevered, tip X) | 1 | actuator stroke >=100 mm (tip travel -15..+85 = 100 mm; model uses 110 mm catalogue stroke); lead 2 mm; light & stiff; ball screw | MISUMI LX26 lead 2, precision grade: LX2602P-...-150 (or -100); example real PN LX2602-B1-A2625-100 (high grade, 100 mm); motor bracket code to configure for NEMA17 | THK KR26 lead 2: KR2602A-0110-P0-01A0 (110 mm, precision) or KR2602A-0160-H0-01A0 | LX2602/LX2605: strokes 100/150 available; repeatability +-0.005 (high) / +-0.003 (precision). KR26: lead 2, strokes 110/160/210 seen | LX26 base price JPY 43,000-66,600 (range across variants) | LX26 repeatability & strokes: excerpt, one source (MISUMI PDF); KR26 PNs verified via Oriental listing; price unverified |
| P03 | Actuator | Y stage (on fixed Y beam) | 1 | actuator stroke >=30 mm (tip travel +/-15 mm; model uses 50 mm catalogue stroke); carries X+Z groups ~4 kg; largest moment ~7 N m (docs/03 5b) - check catalogue MY/MP | MISUMI LX26 (LX2602/LX2602P), shortest stroke >=50 mm; configure on site | THK KR2602A (lead 2) shortest stock stroke (110 seen; shorter strokes unverified) | same families as P01/P02; lead 1-2 mm; 5-10 um/full step | LX26 JPY 43,000-66,600 (see P02) | partial (families verified; min strokes unverified) |
| P04 | Motor | NEMA17 stepper motors, X and Y | 2 | 42 mm frame, 1.5-2 A class, 24 V bus via TMC5160, single shaft 5 mm | Oriental Motor PKP244D15A2 / PKP244D15B2 (PKP series, 42 mm, bipolar) | Oriental Motor PKP245D15A2 (longer, more torque) | PKP244 holding torque 0.42 N.m (legacy PKP244MD15A listing); detent torque not seen | not found | PNs verified; torque of the -D15A2 variant unverified |
| P05 | Motor | NEMA17 stepper motor for Z (optional brake) | 1 | 42 mm; detent torque >> 0.4 mN.m back-drive; brake only if Z group >0.5 kg | Oriental Motor PKP244D15A2 (no brake; baseline) | Oriental Motor PKP244MD15M (PKP244 with electromagnetic brake; legacy listing) or current PKP brake-type equivalent | holding 0.42 N.m; brake type is power-off-activated (typical; unverified for this PN) | not found | PN seen (legacy); current brake PN unverified |
| P06 | Mechanical | Motor brackets + shaft couplings | 3 | NEMA17 to actuator screw; zero-backlash coupling | THK KR20 / KR26 Direct Motor Mount (THK Store) or KR motor wrap | MISUMI LX motor bracket option (selected in LX PN) + MISUMI disc/Oldham coupling (series; PN to configure for 5 mm motor shaft x screw shaft) | direct mount keeps Z length short; motor wrap (fold-back) shortens X/Y length | not found | partial |
| P07 | Microscope | Motorised XY stage for IX73 (W-B) | 1 | travel >=99 x 63 mm (NOT IX3-SSU 76x52); IX73 mount; PC control | Märzhäuser SCANplus IM 120 x 80 for Olympus IX53/IX73/IX83, order no. 00-24-579-0000 (2 mm ball screw, integrated measuring system) | Evident-listed Märzhäuser stage M-MS-IX3-2-2 (120 x 80 mm, 2 mm pitch ball screw, repro 1 um, accuracy 3 um, 2000 g) - via Evident/Olympus channel | all >= 99 x 63 mm; Prior HLD117IX (linear motor, 50 nm encoders) also IX73-compatible | not found (quote required) | Märzhäuser order no. and Prior H117 114x75 travel: excerpt, 2 sources each; ASI travel UNVERIFIED |
| P08 | Microscope | Stage controller + joystick | 1 | USB/RS-232, Micro-Manager support | Märzhäuser TANGO controller (for SCAN IM) | Prior ProScan III controller (for H117) | controllers are stage-specific; M-MS-IX3-2-2 lists Tango, OSIS STC, Objective Imaging OASIS 4i | not found | partial |
| P09 | Microscope | IX-ULWCD long-working-distance condenser (if not owned) | 1 | WD 73 mm, NA 0.3 - required for near-vertical capillary under condenser | Evident/Olympus IX-ULWCD (Olympus part 6-U220) new via Evident Japan | Refurbished IX-ULWCD via Spectra Services / LabX (6-U220-U) | NA 0.30, WD 73 mm, 4 positions for Ø29 mm devices | USD 974 list (NY state contract price file; older) ; USD 864 (2010 VA price list) | spec: reseller excerpts (2 agree); current Evident availability UNVERIFIED |
| P10 | Capillary holder | Collet capillary holder (custom) with inserts OD 1.0/1.5/2.0 | 1 body + 3 insert sets | Ø10x14 envelope target; depth stop; separate face seal with liquid port; V-seat on arm | Custom turned holder (SUS303/PEEK) using Rego-Fix ER8 collets Ø1.0 / Ø1.5 / Ø2.0 (0.5 mm clamping range each) + ER8 mini nut | Eppendorf Universal Capillary Holder + grip heads 0 (1.0-1.1 mm) / 2 (1.4-1.5 mm) - no 2.0 mm head seen | ER8: clamping range 0.5 mm per collet, runout ~0.010 mm (catalogue class); Eppendorf grip head 0 = 1.0-1.1, 1 = 1.2-1.3, 2 = 1.4-1.5 mm | ER8 collet ~USD 45 each (Rego-Fix, retailer); Eppendorf: not found | ER8 sizes verified (multiple vendors); ER8 nut OD vs Ø10 envelope UNVERIFIED (ER8 nuts are typically ~12-16 mm OD) |
| P11 | Capillary holder | Commercial pipette holder with side port (reference/spare, 1.0-2.0 mm) | 1-3 | side/axial port for liquid, sizes 1.0/1.5/2.0 | WPI MPH series (MPH3, MPH4, MPH6S) - supplied for 1.0/1.2/1.5/2.0 mm OD glass; pressure-injection type, no half-cell | Warner Q-series with port: QSW-A15P (1.5 mm) / QSW-T20P (2.0 mm) (straight, side port) | O-ring/gasket clamping (friction-only; rejected as primary fixation in doc 03) | not found | PNs seen in excerpts; port thread / tubing interface UNVERIFIED |
| P12 | Mechanical | Kinematic magnetic break-away mount (Z carriage <-> arm) | 1 (+1 spare top plate) | repeatable re-seat; releases on collision; holds ~0.1-0.2 kg arm+holder | Thorlabs KB25/M (25 x 25 mm, magnetic, ball/V-groove); top KBT25/M, bottom KBB25/M | Thorlabs KB50/M (50 x 50 mm; higher holding force) | KB25/M: holding force 3.6 lbf (~16 N); angular repeatability mean ~6 urad; KB50/M: 6.25 lbf (~28 N), mean ~12 urad | KB25/M USD 75.60; KBT25/M or KBB25/M USD 39.90 each | verified (Thorlabs + reseller excerpts) |
| P13 | Mechanical | Exchangeable angle blocks 8 / 20 / 30 deg | 3 | two dowels + clamp screw; tip within +-1 mm nominal | Custom CNC (MISUMI meviy CNC milling, upload 3D CAD for instant quote) | Local machine shop (A5052/A2017, anodised) | engraved angle; dowel-pin location (MISUMI dowel pins, series) | not found (meviy instant quote) | n/a (custom) |
| P14 | Mechanical | Dog-leg arm (115 mm, 12x12 thin section) | 1 (+1 spare) | stiff, thin; tubing clip groove on side | Custom CNC via MISUMI meviy (A7075 or SUS304) | Local machine shop | static sag absorbed by image calibration | not found | n/a (custom) |
| P15 | Mechanical | Carriage brackets (X carriage->Z body, Y carriage->X beam), tubing clamps | set | match actuator table hole patterns | Custom CNC via MISUMI meviy | MISUMI LX26 attachment jig / standard brackets where they fit | - | not found | n/a (custom) |
| P16 | Frame | Base plate, 15 mm aluminium, slotted for table grid | 1 | M6/25 mm (or 1/4-20/1") slots, +-15 mm X/Y, +-2 deg yaw | MISUMI meviy CNC milling (plate with slots, A5052) | MISUMI configurable aluminium plate (series; configure holes/slots) | flatness and slot pattern | not found (instant quote on meviy) | n/a (custom) |
| P17 | Frame | Posts, aluminium extrusion 80x80 | 2 | 80x80, 8-series; length per M1 (stage height) + adjustment slots | MISUMI HFS8-8080 (cut to length, 50-4000 mm) | MISUMI 80x80 8-series base-40 variants (one closed side / milled surfaces) | HFS8-8080: 4.57 kg/m, section 1691 mm2 | USD 43.60/m (>=300 mm); USD 13.00 each (<300 mm) | price/spec: excerpt, one source |
| P18 | Frame | Y beam, aluminium extrusion 80x80, ~390 mm | 1 | twice-supported; flat mounting face for Y actuator | MISUMI HFS8-8080 (L~390) | MISUMI 80x80 extrusion with milled surfaces (8 series) | see P17 | ~USD 17 (0.39 m x USD 43.60/m) | derived |
| P19 | Frame | X support beam, aluminium extrusion 40x80 (cantilever) | 1 | 40x80 minimum; length ~X body | MISUMI HFS8-4080 | MISUMI 40x80 8-series base-40 | 8-series 40x80 | not found | partial (PN family seen, price not) |
| P20 | Frame | Extrusion fasteners: brackets, post-assembly nuts, diagonal braces, jack screw | set | 8-series slot; +-20 mm height adjust | MISUMI HFS8 brackets and post-insertion nuts (series; configure) | MISUMI diagonal/angle brackets (series) | - | not found | n/a |
| P21 | Consumable | Glass capillaries class S: OD 1.0 / ID 0.58 | 1 pack | borosilicate, no filament | WPI 1B100-4 (1.0/0.58, 4 in) | Narishige G-1 (1.0/0.6, 90 mm, 500/pk; Japanese supplier) | OD 1.0 mm | not found | WPI: manifest S14; Narishige: excerpt |
| P22 | Consumable | Glass capillaries class M: OD 1.5 / ID 0.84-0.86 | 1 pack | borosilicate, no filament | WPI 1B150-4 (1.5/0.84) | Sutter B150-86-10 (1.5/0.86, 10 cm) | OD 1.5 mm | not found | WPI/Sutter: manifest S14 |
| P23 | Consumable | Glass capillaries class L: OD 2.0 / ID 1.12 | 1 pack | borosilicate, no filament | WPI 1B200-4 (2.0/1.12) | Narishige G-2 (series; ID unverified) | OD 2.0 mm | not found | manifest S14 |
| P24 | Consumable | Glass capillaries class L': thin wall OD 2.00 / ID 1.56 | 1 pack | borosilicate, no filament, for 0.8-1 mm objects | Sutter B200-156-10 (2.00/1.56, 10 cm, thin wall, no filament) | WPI thin-wall 2.00/1.56 no filament (10 cm, 250/pk; 15 cm, 100/pk) - likely TW200-4; exact PN to confirm on WPI site | OD 2.00, ID 1.56 | not found | Sutter PN: excerpt; WPI PN UNVERIFIED |
| P25 | Fluidics | PTFE/FEP tubing 1/16" OD | 1 roll (~3 m used) | 1/16" OD, bore 0.030" (0.75 mm) class, liquid-filled, bend radius >=25 mm | IDEX Health & Science FEP tubing 1/16" OD x 0.030" ID, natural, 50 ft: 1520L | IDEX FEP 1/16" OD other bores (0.020" / 0.040"; family 152x, configure) | FEP, low-pressure fluidics, 1/16" OD | not found | 1520L verified (IDEX store) |
| P26 | Fluidics | Fittings 1/4-28 flat-bottom for 1/16" tubing (+ferrules, unions) | 1 kit | PEEK flangeless, finger-tight | IDEX XP-235X flangeless fitting, short, PEEK, 1/4-28 FB, 1/16" (10/pk) | IDEX flangeless ferrule blue ETFE 1/16" 1/4-28 FB (10/pk; PN P-200X - unverified in this session) | 1/4-28 flat-bottom standard, low-pressure | XP-235X USD 62.23 (IDEX US store; per 10-pack as listed) | XP-235X verified; ferrule PN unverified |
| P27 | Fluidics | Pump interface: Luer to 1/4-28 adapter (Harvard) / direct 1/4-28 (Tecan Cavro) | 1-2 | connect syringe (Luer) or pump valve port to 1/16" tubing | IDEX Luer adapters, female Luer to 1/4-28 (series; exact PN to configure on IDEX site) | Tecan Cavro valve ports accept 1/4-28 fittings directly (to confirm per pump model) | - | not found | series only |
| P28 | Electronics | Motion controller (G-code / serial, >=3 axes, >=6 NC inputs) | 1 | PC-accessible; SPI to TMC5160; homing, soft limits | Duet3D Duet 3 Mainboard 6HC (6 on-board TMC5160 drivers, 6.3 A peak, 9 IO ports, RepRapFirmware, USB/Ethernet) | BIGTREETECH Octopus Pro (STM32H723) + TMC5160T Pro drivers (Marlin/Klipper) | see item | Duet 6HC ~USD 231 (retailer, sold out) ; AliExpress listing USD 154 (clone risk) | Duet driver type verified (Duet docs + forum); Trinamic specs: excerpts |
| P29 | Electronics | TMC5160 stepper drivers (only if controller has sockets) | 3 (+1 spare) | SPI, external MOSFETs, 24 V, 1.5-2 A | BIGTREETECH TMC5160T Pro V1.0 (up to 56 V, SPI) | BIGTREETECH EZ5160 Pro (8-48 V, 2.5 A RMS / 3 A peak, SPI, EZ socket) | see item | TMC5160T Pro: USD 133.19 per 4-pack (Amazon) | excerpt, one source each |
| P30 | Electronics | Home switches, NC / fail-safe (X out, Y front, Z top) + optional far limits | 3 (+3 optional) | NC or fail-safe output; repeatable | Omron EE-SX672 / EE-SX674 slot photomicrosensor (5-24 V, NPN, Light-ON/Dark-ON selectable, 5 mm slot) | Panasonic PM-T45 / PM-L25 (6 mm slot, NPN, Light-ON & Dark-ON outputs, 5-24 V) | optical: 1 kHz response (EE-SX67x); D2VW price USD 3.58-5.45 | D2VW-5-1HS USD 3.6-5.5 ; optical: not found | verified (multiple distributors) |
| P31 | Electronics | 24 V DC PSU (~150 W) | 1 | 24 V, >=6 A, fused | Mean Well LRS-150-24 (24 V 6.5 A, 156 W, enclosed, 30 mm low profile) | Mean Well SDR-120-24 (24 V 5 A, 120 W, DIN rail, PFC) | see item | not found (JPY); widely stocked | verified (several distributors) |
| P32 | Safety | E-stop push button (2NC) | 1 | 2 NC contacts for dual-channel safety relay | IDEC XW1E-BV402M-R (40 mm push-lock/pull, 2NC, 22 mm hole) | IDEC XA1E-BV3U02R (16 mm, 2NC, IP65) | 2NC, IP65 | not found | verified |
| P33 | Safety | Safety relay / contactor cutting motor 24 V (logic stays on) | 1 | dual-channel E-stop, cuts driver VM only | Omron G9SE-201 (24 VDC, 2 safety NO + 1 aux, Cat.4/PLe, 17.5 mm DIN) | IDEC HR6S-AF1C safety relay module (Cat.4, push-in) | Cat.4 PLe (G9SE) | IDEC HR6S-AF1C USD 357 ; G9SE: not found | G9SE verified; DC switching rating at driver inrush UNVERIFIED |
| P34 | Wiring | Cable chains (X on Y group; Y on frame) | 2 | small inner height for 2 motor + 2 switch cables; R >= cable min. | igus E2i.15 / B15i series (openable inner radius; configure width/radius) | igus E2.15 series (openable outer radius) | B15i example PN B15I.050.075.0 = 50 mm inner width, R75 (too wide - choose smaller width) | not found (igus prices on request / configurator) | series verified; exact PN to configure |
| P35 | Wiring | Motor (shielded) and switch (twisted pair) cables, chain-rated | ~6 m each | continuous flex; shielded motor cables | igus chainflex shielded motor/control cable (series; exact CF type unverified) | Oriental Motor motor extension cables (for PKP connector types) | - | not found | UNVERIFIED |
| P36 | Electronics | Enclosure, DIN rail, fuses, terminal blocks, USB cable | 1 set | - | Takachi / IDEC control box (series) | Phoenix / Wago DIN terminals (series) | - | not found | n/a |
| P37 | Frame | Table mounting hardware | 1 set | M6 (25 mm grid) or 1/4-20 (1") cap screws + washers | MISUMI cap screws/washers (series) | Thorlabs HW-KIT (series, unverified) | - | not found | n/a |
| P38 | Fluidics | Syringe pump (existing Harvard or Tecan) - no purchase | 0 | existing; serial control later | Harvard Apparatus (model TBD, M17) | Tecan Cavro (Centris/XLP, TBD) | syringe 25-100 uL for resolution (doc 08) | - | n/a |
| P39 | Microscope | SBS plate insert / holder for the motorised XY stage | 1 | holds SBS-footprint plates (6-96 well) flat on the chosen stage (P07); defines the plate datum (M3) | Stage vendor's multiwell-plate insert for the chosen stage (Märzhäuser / Evident / Prior) — configure with the stage quote |  | SBS 127.76 x 85.48 footprint; flatness; clips below plate top | not found | n/a (depends on P07) |
| P40 | Fluidics | Syringe for the existing pump (gas-tight) | 2 | volume resolution for 0.5-2 uL pick volumes; Luer or 1/4-28 outlet | Hamilton 1700-series gas-tight syringe, 25-100 uL (series; confirm pump clamp size) | Tecan/Cavro syringe matching the pump model (if Tecan) | 25-100 uL; PTFE Luer lock | not found | unverified (series only) |
| P41 | Fluidics | Optional pinch/NC valve and pressure tee on the fixed side | 1 | fast suction pulse decoupled from the pump (CellSorter principle); pressure reading for later pick confirmation | Normally-closed solenoid pinch valve for 1/16 in tubing (series; e.g. from fluidics vendors) | 1/4-28 PEEK tee + pressure sensor | NC, low dead volume | not found | unverified |
| P42 | Electronics | Z reference switch (below the condenser) | 1 | NC, repeatable to <10 um; mounted on the Z body at the height set from M8 | Omron EE-SX672 slot photomicrosensor (same as P30) |  | repeatability; small size | see P30 | see P30 |

## Sources per item

- **P01** <https://catalog.orientalmotor.com/item/linear-actuators-linear-slides-only/thk-lm-guide-actuator-kr20/kr2001a-0080-h0-01a0>, <https://catalog.orientalmotor.com/item/linear-actuators-linear-slides-only/thk-lm-guide-actuator-kr20/kr2001a-0030-p0-01a0>, <https://www.thk.com/jp/en/products/lm_guide_actuator/selection/0008/>, <https://us.misumi-ec.com/pdf/fa/2014/P1_0417.pdf>, <https://www.orientalmotor.com/linear-actuators/compact-linear-actuators-drs-series-absolute-encoder.html>, <https://www.monotaro.com/p/1564/1826/>
- **P02** <https://us.misumi-ec.com/vona2/detail/110300075270/>, <https://in.misumi-ec.com/pdf/fa/2014/p1_421_001_p1_423.pdf>, <https://www.radwell.com/en-US/Buy/MISUMI/MISUMI/LX2602-B1-A2625-100/>, <https://catalog.orientalmotor.com/item/linear-actuators-linear-slides-only/thk-lm-guide-actuator-kr26/kr2602a-0110-0-01a0>, <https://jp.misumi-ec.com/maker/misumi/mech/special/actuator_portal/lx/detail/>
- **P03** <https://us.misumi-ec.com/vona2/detail/110300075270/>, <https://catalog.orientalmotor.com/viewitems/linear-actuators-linear-slides-only/thk-lm-guide-actuator-kr20>
- **P04** <https://catalog.orientalmotor.com/item/2-phase-bipolar-stepper-motors/42mm-pkp-series-2-phase-bipolar-stepper-motors/pkp244d15a2>, <https://catalog.orientalmotor.com/item/42mm-frame-stepper-motors/42mm-pkp-series-2-phase-bipolar-stepper-motors/pkp245d15a2>, <https://www.orientalmotor.com/stepper-motors/2-phase-stepper-motors-pkp-series.html>
- **P05** <https://catalog.orientalmotor.com/item/all-categories-legacy-products/legacy-pkp-series-2-phase-bipolar-stepper-motors/pkp244md15m-1>, <https://www.orientalmotor.com/products/pdfs/2018-2019/549%20PKP%20Series%20Catalog.pdf>
- **P06** <https://www.thkstore.com/kr20-direct-motor-mount.html>, <https://www.thkstore.com/skr20-motor-wrap-3-o-clock.html>, <https://www.thk.com/jp/en/products/lm_guide_actuator/full_ball/kr20/ab_direct_standard/>
- **P07** <https://products.marzhauser.com/Datenblaetter/EN/48-24-581-0000_SCAN_IM_120_80_DICTA_EN.pdf>, <https://products.marzhauser.com/en/data/scanplus-im-c5838>, <https://www.wolflabs.co.uk/laboratory-equipment/miscellaneous-products/e0433735/10433840>, <https://www.prior.com/product/proscan-h117e1xd-inverted-stage>, <https://photos.labwrench.com/equipmentManuals/14699-5711.pdf>, <https://www.prior.com/Content/Downloads/Evident-Olympus-IX73-inverted-microscope.pdf>, <https://www.asiimaging.com/products/stages/xy-inverted-stages/ms-2000-flat-top-xyz-automated-stage/>
- **P08** <https://www.wolflabs.co.uk/laboratory-equipment/miscellaneous-products/e0433735/10433840>, <https://www.prior.com/product/proscan-h117e1xd-inverted-stage>, <https://www.asiimaging.com/products/stages/xy-inverted-stages/ms-2000-xyz-automated-stage/>
- **P09** <https://spectraservices.com/product/6-u220.html>, <https://spectraservices.com/product/6-u220-u.html>, <https://www.labx.com/item/olympus-ix-ulwcd-long-working-distance-condenser/DIS-41276-6-U220>, <https://online.ogs.ny.gov/purchase/spg/pdfdocs/1260023072PL_OlympusAmerica.pdf>, <https://www.tengrant.com/upLoad/file/20190331/IX73-IX83_system_chart.pdf>
- **P10** <https://shop.fischerspindle.com/Collets/ER8/en>, <https://www.freertool.com/products/9-pc-collet-set-7mm-5mm-er8-style-collet>, <https://www.toolsengg.com/collets-64/er-collets/er-standard-collets/er8-standard-collets>, <https://www.fishersci.pt/shop/products/grip-head-0/11886884>, <https://www.eppendorf.com/product-media/doc/en/142967_Supplement-sheet/Eppendorf_Cell-Technology_Instructions-use_Universal-capillary-holder.pdf>
- **P11** <https://www.wpiinc.com/var-3781-microelectrode-holder-mph6s>, <https://wpiinc.com/products/var-3819-microelectrode-holder-mph3>, <https://www.warneronline.com/q-series-holders-for-Warner-and-some-early-axon>, <https://www.harvardapparatus.com/media/brochures/Warner_Microelectrode_Holders.pdf>, <https://products.narishige-group.com/group1/HI-7/injection/english.html>, <https://products.narishige-group.com/group1/HI-9/injection/english.html>
- **P12** <https://www.thorlabs.com/item/KB25_M>, <https://www.thorlabs.com/thorproduct.cfm?partnumber=KB50/M>, <https://www.thorlabs.com/kinematic-bases2>
- **P13** <https://cdn.meviy.misumi-ec.com/en_us-us/>, <https://www.misumi.co.jp/english/news/press_240708>
- **P14** <https://cdn.meviy.misumi-ec.com/en_us-us/>
- **P15** <https://us.misumi-ec.com/vona2/detail/110302392540/>, <https://cdn.meviy.misumi-ec.com/en_us-us/>
- **P16** <https://cdn.meviy.misumi-ec.com/en_us-us/>, <https://www.misumi.co.jp/english/news/press_250512_3>
- **P17** <https://us.misumi-ec.com/pdf/fa/2010/p2319.pdf>, <https://us.misumi-ec.com/vona2/detail/110302690740/>
- **P18** <https://us.misumi-ec.com/vona2/detail/110302691870/>, <https://us.misumi-ec.com/vona2/detail/110302690740/>
- **P19** <https://us.misumi-ec.com/vona2/detail/110302690310/>
- **P20** <https://it.misumi-ec.com/files/images/products/docs/nutsforaluminiumextrusions.pdf>
- **P21** <https://www.wpiinc.com/clientuploads/pdf/catalog/pages/capillaryglass.pdf>, <https://products.narishige-group.com/group1/G-1_1.2_1.5_2_3/pipette/english.html>, <https://www.tritechresearch.com/G-1.html>
- **P22** <https://www.wpiinc.com/clientuploads/pdf/catalog/pages/capillaryglass.pdf>, <https://www.autom8.com/shop/micropipette-fabrication/glass/borosilicate-glass1-5-x-0-86mm-x-10cm-250-pcs/>, <https://products.narishige-group.com/group1/G-1_1.2_1.5_2_3/pipette/english.html>
- **P23** <https://wpiinc.com/products/var-1972-standard-glass-capillaries-2mm-od>, <https://www.wpiinc.com/clientuploads/pdf/catalog/pages/capillaryglass.pdf>
- **P24** <https://www.fishersci.com/shop/products/bor-glass-tubing-225-pk/NC9051667>, <https://www.sutter.com/micropipette/glass-0-0>, <https://wpiinc.com/products/var-3709-thin-wall-glass-capillaries>, <https://wpiinc.com/products/var-tw100-3-thin-wall-glass-capillaries-no-filament>
- **P25** <https://www.idex-hs.com/store/product-detail/fep_tubing_1_16_od_x_030_id_natural_50ft/1520l>, <https://www.idex-hs.com/store/fluidics/fluidic-connections/tubing/fluoropolymer-tubing/teflonr-fep-tubing.html>
- **P26** <https://www.idex-hs.com/store/product-detail/flangeless_fitting_short_peek_1_4_28_flat_bottom_for_1_16_od_natural_10_pack/xp-235x>, <https://www.coleparmer.com/i/idex-flangeless-ferrule-blue-etfe-1-16-od-tubing-1-4-28-flat-bottom-10-pk/0193930>
- **P27** <https://www.idex-hs.com/store/products/fluidics/fluidic_connections/connectors/luer_adapters>, <https://scipro.com/idex-fluidics-connectors-luer-adapters/>
- **P28** <https://docs.duet3d.com/Duet3D_hardware/Duet_3_family/Duet_3_Mainboard_6HC_Hardware_Overview>, <https://www.duet3d.com/duet3mainboard6hc>, <https://www.analog.com/en/products/tmcm-3216.html>, <https://www.trinamic.com/products/modules/details/tmcm-3110/>, <https://www.mouser.com/new/trinamic/trinamic-tmcm-3110-stepper-motor-drivers/>
- **P29** <https://biqu.equipment/products/tmc5160-pro-v1-0>, <https://www.amazon.com/BIGTREETECH-TMC5160-Stepper-Drivers-heatsink/dp/B0B8HZXWPP>, <https://dfh.fm/products/btt-ez5160-pro-stepper-motor-driver>
- **P30** <https://www.ia.omron.com/product/item/2224/>, <https://datasheet.octopart.com/EE-SX672-Omron-datasheet-134124.pdf>, <https://industry.panasonic.com/global/en/products/fasys/sensor/micro/number/pm-t45>, <https://industry.panasonic.com/global/en/products/fasys/sensor/micro/number/pm-l25>, <https://omronfs.omron.com/en_US/ecb/products/pdf/en-d2f.pdf>, <https://octopart.com/d2vw-5-1hs-omron-47505>
- **P31** <https://www.mouser.com/ProductDetail/MEAN-WELL/LRS-150-24?qs=vDxCgdWo2h%2Bym5KOpEI%2Bpw%3D%3D>, <https://us.rs-online.com/product/mean-well/lrs-150-24/70696543/>, <https://powersupplymall.com/products/mean-well-sdr-120-24-single-output-industrial-power-supply-120w-24v-din-rail>
- **P32** <https://us.rs-online.com/product/idec-corporation/xw1e-bv402m-r/70172752/>, <https://www.newark.com/idec/xa1e-bv3u02-r/switch-emergency-stop-2nc-250vac/dp/05R0253>, <https://www.tme.com/us/en-us/details/xa1e-bv3u02r/panel-mount-switches-standard-16mm/idec/>
- **P33** <https://www.ia.omron.com/products/family/3419/>, <https://www.digikey.com/en/products/detail/omron-automation-and-safety/G9SE-201/7495167>, <https://automation.omron.com/en/us/products/family/G9SE>
- **P34** <https://www.igus.com/product/series-E2i-15>, <https://www.igus.com/product/series-E2-15>, <https://www.tme.com/us/en-us/details/b15i.050.075.0/cable-chains/igus/>
- **P35** <https://www.igus.com/product/series-E2i-15>

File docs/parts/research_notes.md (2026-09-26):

# Stage-1 parts research notes (workflow W-B side-tower picker)

Retrieval date: 2026-09-26. Method: web search only. Vendor pages (MISUMI, THK, Oriental, Evident, Thorlabs, IDEX) could not be opened, so every value below comes from a search-result excerpt of the named page. "Unverified" means that no excerpt showed the value, or only one weak source did. Prices are **approximate**, in the currency found, and several are old or from non-Japanese resellers. Get quotes before ordering. The line items are in `candidates.csv` (P01–P38).

Baseline travels come from `cad/params.py` `layout("WB")`: tip X 100 mm (-15…+85), Y 30 mm, Z 50 mm.

## 1. Actuators (P01–P06): the most important decisions

**Z (P01).** The THK KR20 with a 1 mm lead is a real, stocked product. Stock PNs seen through Oriental Motor's THK listing:

- KR2001A-0030/-0080/-0130
- accuracy suffix `0` (normal), `H0` (high accuracy) or `P0` (precision)
- `-01A0` = no cover, `-11A0` = cover

No 50 mm stock stroke was seen, so **KR2001A-0080-P0-01A0 (or -H0-)** is the lean. The 80 mm stroke gives 30 mm of margin for touch-off and capillary change. Monotaro lists KR2001A semi-order items, so the part can be bought in Japan. THK sells a "KR20 Direct Motor Mount" for NEMA17.

- **Unverified:** the numeric repeatability per KR grade. The THK "Accuracy Standards (KR)" page exists but its values were not visible. Do not quote ±0.003 for KR20 until the THK table is read.
- **Price not found.** The only figure was a used unit on eBay (~USD 108 + shipping).
- Alternatives:
  - MISUMI LX20, lead 1 (LX2001P). Repeatability ±0.005 (high grade) / ±0.003 (precision), from the MISUMI LX20 PDF excerpt.
  - Oriental DRS2 guide type with brake and AZ absolute encoder. Repeatability ±0.01 (rolled) / ±0.003 (ground). This is the "industrial, closed-loop" route, but it brings its own driver and does not use the TMC5160 controller. The exact DRS2 PN (lead, stroke, brake) must be configured; the listing PNs seen (DRSM42RG-04B2AZMK) do not reveal the lead.

**X (P02).** Lean **MISUMI LX26, lead 2, precision grade (LX2602P), 150 mm stroke**, or **THK KR2602A-0110-P0-01A0** (110 mm).

- Why not 100 mm: the stroke would equal the required travel exactly, leaving no margin to the mechanical stops.
- LX2602/LX2605 is available in 100 and 150 mm strokes, repeatability ±0.005 / ±0.003 (MISUMI PDF excerpt). One real PN was seen: LX2602-B1-A2625-100.
- MISUMI Japan base price range for LX26: **JPY 43,000–66,600** (search excerpt, approximate).

**Y (P03).** Stroke ≥30 mm, but Y carries the whole X cantilever (≈2.5–3 kg with a large overhang). A width-26 class body is therefore the safer choice (LX26 or KR26, shortest stroke ≥50 mm). The shortest stock strokes were **not verified** (KR26: only 110/160/210 seen). A moment-load check (Mp/My) against the carriage rating is still needed.

**Motors (P04/P05).** Oriental PKP244/PKP245 (42 mm; PKP244 holding torque 0.42 N·m). A brake version exists (legacy PKP244MD15M). Per doc 03 §5, no brake is needed with a 1 mm lead at 0.3 kg; keep the brake as an option. Detent torque was not found.

**Budget signal.** Industrial stages on all three axes (KR20 + 2 × LX26/KR26) plausibly consume **JPY 150–230k** before motors, controller, frame and holder. This is an estimate from the LX26 price range only. Hitting ~JPY 200k for the full picker probably means either:

- Arch. B on Y (doc 04 allows it), or
- accepting ~JPY 250–350k in total.

Reliability-over-price favours the second.

**Lead-time risk.** THK KR is often built to order (semi-order at Monotaro), so expect 2–6 weeks (unverified). MISUMI LX is usually a short, fixed lead time. Oriental ships from Japanese stock.

## 2. Microscope side (P07–P09): longest lead times

**Motorised stage (P07).**

- **Märzhäuser SCANplus IM 120 × 80 for IX53/IX73/IX83, order no. 00-24-579-0000.** 2 mm ball screw with an integrated measuring system (excerpt of the Märzhäuser datasheet and order info).
- The same class of stage is sold through the Olympus/Evident channel as **M-MS-IX3-2-2**: 120 × 80 mm, 2 mm pitch, reproducibility 1 µm, accuracy 3 µm, 2000 g, controllers Tango / OSIS / OASIS (WolfLabs listing).
- **Prior ProScan H117E1XD / H117N1XD for IX3:** 114 × 75 mm, 1 mm ball screw, encoded (E) version. Travel confirmed by two sources. The margin over 99 × 63 is smaller but sufficient.
- **ASI MS-2000 flat-top** is listed as IX73-compatible. Its travel was reported as both 120 × 110 and 120 × 75, so it is **unverified**.
- **No Evident-native motorised stage other than the IX3-SSU (76 × 52, insufficient) was found.**
- No prices were found; all require a quote.
- Lean: SCAN IM 120 × 80, via Evident as M-MS-IX3-2-2 if the lab wants a single Evident support channel, or Prior H117E1XD if the lab already uses Prior. All three brands are supported by Micro-Manager.

**Stage controller (P08).** Stage-specific (Märzhäuser Tango, Prior ProScan III, ASI MS-2000). Usually quoted with the stage.

**IX-ULWCD (P09).** Olympus part 6-U220, NA 0.30, WD 73 mm, 4 positions for Ø29 mm devices (Spectra Services and LabX excerpts agree). Old US contract list price is ~USD 974 (NY) / USD 864 (VA 2010). Refurbished units are offered by Spectra Services.

- **Risk:** one excerpt says the IX-ULWCD is "not available in some areas". Ask Evident Japan now. If it is unavailable, the fallback is the tilted pillar with LED ring (doc 03 §8), or a refurbished unit.

## 3. Capillary holder and break-away (P10–P12)

- **No off-the-shelf holder covers 1.0/1.5/2.0 mm with a side port and a positive collet.**
  - The Eppendorf Universal Capillary Holder grip heads cover 1.0–1.1 (head 0), 1.2–1.3 (head 1) and 1.4–1.5 (head 2). No 2.0 mm head was seen.
  - Narishige HI-7/HI-9 take 1.0 mm only.
  - The WPI MPH series (MPH3/4/6S) and the Warner Q-series with port (QSW-A15P = 1.5 mm, QSW-T20P = 2.0 mm) cover the sizes, but they clamp with O-rings or gaskets. Doc 03 rejects friction-only clamping as the primary fixation.
  - These are still useful for early pick tests.
- **Custom collet (lean).** A turned body using standard **Rego-Fix ER8 collets Ø1.0 / 1.5 / 2.0** (0.5 mm clamping range each, ~USD 45 each at retail), with a separate face seal and a 1/4-28 flat-bottom side port. The port then takes the IDEX XP-235X fitting directly.
  - **Risk 1:** an ER8 nut is likely larger than the Ø10 mm envelope (typical ~12–16 mm, **unverified**). Re-run `analysis.py` with a larger `HOLDER_D`.
  - **Risk 2:** steel collets can chip glass. Use a thin polymer sleeve or a torque limit, and test.
- **Break-away (P12).** Thorlabs **KB25/M**: 16 N (3.6 lbf) magnetic hold, ball/V-groove, USD 75.60 list. KB50/M holds 6.25 lbf. Lean KB25/M for the 0.3 kg Z group; Thorlabs Japan stocks it. Check that the release force at the tip (115 mm lever) protects the plate and does not release during landing.

## 4. Frame and custom parts (P13–P20, P37)

- MISUMI **HFS8-8080**: 4.57 kg/m, USD 43.60/m (MISUMI US excerpt). HFS8-4080 exists (price not seen). Order with milled or tapped ends.
- Base plate, angle blocks, dog-leg arm and brackets: **MISUMI meviy** (upload STEP for an instant quote; ships in as little as 1 day for simple parts). Only freeze after the actuator PNs (hole patterns) and M1/M15 are known.

## 5. Fluidics and consumables (P21–P27)

**Glass.**

| Class | Candidates |
|---|---|
| S (1.0 mm) | WPI 1B100-4; Narishige G-1 (1.0/0.6, 90 mm, 500/pk; Japanese maker) |
| M (1.5 mm) | WPI 1B150-4; Sutter B150-86-10 |
| L (2.0 mm) | WPI 1B200-4 |
| L′ (2.00/1.56 thin wall) | Sutter B200-156-10 (confirmed); WPI thin-wall no-filament 2.00/1.56, 10 cm × 250 and 15 cm × 100, exact PN (probably TW200-4) **unverified** |

Japanese stock of the thin-wall glass is unknown.

**Tubing and fittings.** IDEX FEP 1/16" × 0.030" natural, 50 ft = **1520L** (verified). IDEX **XP-235X** PEEK flangeless 1/4-28 FB fitting (USD 62.23 for a 10-pack on the IDEX store). The ferrule PN P-200X was not confirmed in this session.

**Pump interface.** Use IDEX Luer adapters (female Luer to 1/4-28), exact PN to configure, for Harvard syringes. Tecan Cavro valves are generally 1/4-28, to be confirmed per model (M17).

## 6. Electronics and safety (P28–P36)

**Controller.** Lean **Duet 3 Mainboard 6HC**. It has 6 on-board TMC5160 drivers (current boards all ship with 5160), 6.3 A peak, 9 IO ports and a G-code interface over USB/Ethernet, which matches the SpheroidPicker precedent. Price ~USD 231 at a US retailer (sold out). Buy genuine: AliExpress "Duet" listings (~USD 154) are clone risks.

- Alternatives:
  - BTT Octopus Pro + BTT TMC5160T Pro drivers (USD 133 per 4-pack).
  - ADI Trinamic TMCM-3110 (industrial, 3-axis, 9–52 V, up to 4 A, TMCL rather than G-code).
  - TMCM-3216 (3-axis, 2 A RMS, 10–30 V).

**Home switches.** Omron **EE-SX672/674** (5–24 V, NPN, Light-ON/Dark-ON selectable) or Panasonic PM-T45/PM-L25. Wire them fail-safe. Omron D2F-01L / D2VW-5-1HS micro switches (USD 3.6–5.5) are the mechanical NC option.

**PSU.** Mean Well **LRS-150-24** (24 V, 6.5 A), or SDR-120-24 for DIN rail.

**E-stop.** IDEC **XW1E-BV402M-R** (40 mm, 2NC) or XA1E-BV3U02R (16 mm, 2NC).

**Safety relay.** Omron **G9SE-201** (24 VDC, 2 safety NO, Cat.4/PLe) or IDEC HR6S-AF1C (~USD 357). **Unverified:** whether the G9SE contacts are rated for switching the driver VM bus, including capacitor inrush, directly. If not, add a force-guided relay or small DC contactor downstream.

**Cable chains.** igus E2i.15/B15i or E2.15, configured to width and radius. Prices are on request.

## 7. Top risks and uncertainties

1. **IX-ULWCD availability** (possible regional discontinuation). Confirm with Evident Japan before anything else; the whole near-vertical concept depends on it.
2. **Motorised stage lead time and cost** (quote-only; not in the picker budget). The choice also fixes the stage envelope that the tower must clear (freeze-gate item).
3. **Budget.** Industrial stages on all three axes likely push the picker above JPY 200k (my estimate: 250–350k).
4. **KR20 grade repeatability numbers and Y minimum strokes are unverified.** Read the THK KR accuracy table and the MISUMI LX26 stroke list (vendor pages blocked here) before choosing the grade.
5. **Holder envelope with ER8 collets** is probably larger than Ø10 mm. This changes the light-cone and condenser-clearance numbers, so re-run the analysis.

## 8. URLs used

- https://catalog.orientalmotor.com/item/linear-actuators-linear-slides-only/thk-lm-guide-actuator-kr20/kr2001a-0080-0-01a0
- https://catalog.orientalmotor.com/item/linear-actuators-linear-slides-only/thk-lm-guide-actuator-kr20/kr2001a-0080-h0-01a0
- https://catalog.orientalmotor.com/item/linear-actuators-linear-slides-only/thk-lm-guide-actuator-kr20/kr2001a-0030-p0-01a0
- https://catalog.orientalmotor.com/viewitems/linear-actuators-linear-slides-only/thk-lm-guide-actuator-kr20
- https://catalog.orientalmotor.com/item/linear-actuators-linear-slides-only/thk-lm-guide-actuator-kr26/kr2602a-0110-0-01a0
- https://www.thk.com/jp/en/products/lm_guide_actuator/full_ball/kr20/
- https://www.thk.com/jp/en/products/lm_guide_actuator/selection/0008/
- https://www.thk.com/jp/en/products/lm_guide_actuator/full_ball/kr20/ab_direct_standard/
- https://tech.thk.com/en/products/pdf_download.php?file=E_02_LMGuideActuator.pdf
- https://www.thkstore.com/kr20-direct-motor-mount.html
- https://www.thkstore.com/skr20-motor-wrap-3-o-clock.html
- https://www.monotaro.com/p/1564/1826/
- https://www.monotaro.com/p/1574/3229/
- https://www.ebay.com/itm/224442289353
- https://us.misumi-ec.com/pdf/fa/2014/P1_0417.pdf
- https://us.misumi-ec.com/vona2/detail/110300075020/
- https://us.misumi-ec.com/vona2/detail/110300075270/
- https://in.misumi-ec.com/pdf/fa/2014/p1_421_001_p1_423.pdf
- https://jp.misumi-ec.com/maker/misumi/mech/special/actuator_portal/lx/detail/
- https://www.radwell.com/en-US/Buy/MISUMI/MISUMI/LX2602-B1-A2625-100/
- https://us.misumi-ec.com/vona2/detail/110302392540/
- https://www.orientalmotor.com/linear-actuators/compact-linear-actuators-drs-series-absolute-encoder.html
- https://catalog.orientalmotor.com/item/all-categories-legacy-products/42mm-guide-drs-absolute-linear-actuators/drsm42rg-04b2azmk-azd-k
- https://catalog.orientalmotor.com/item/2-phase-bipolar-stepper-motors/42mm-pkp-series-2-phase-bipolar-stepper-motors/pkp244d15a2
- https://catalog.orientalmotor.com/item/42mm-frame-stepper-motors/42mm-pkp-series-2-phase-bipolar-stepper-motors/pkp245d15a2
- https://catalog.orientalmotor.com/item/all-categories-legacy-products/legacy-pkp-series-2-phase-bipolar-stepper-motors/pkp244md15m-1
- https://www.orientalmotor.com/stepper-motors/2-phase-stepper-motors-pkp-series.html
- https://www.orientalmotor.com/products/pdfs/2018-2019/549%20PKP%20Series%20Catalog.pdf
- https://products.marzhauser.com/Datenblaetter/EN/48-24-581-0000_SCAN_IM_120_80_DICTA_EN.pdf
- https://products.marzhauser.com/en/data/scanplus-im-c5838
- https://products.marzhauser.com/en/data/scan-im-c5836
- https://scop-pro.com/index.php?controller=attachment&id_attachment=22
- https://www.wolflabs.co.uk/laboratory-equipment/miscellaneous-products/e0433735/10433840
- https://www.prior.com/product/proscan-h117e1xd-inverted-stage
- https://www.prior.com/product/proscan-h117n1xd-inverted-stage
- https://www.prior.com/product/proscan-hld117ix-linear-motor-stage
- https://www.prior.com/Content/Downloads/Evident-Olympus-IX73-inverted-microscope.pdf
- https://photos.labwrench.com/equipmentManuals/14699-5711.pdf
- https://www.asiimaging.com/products/stages/xy-inverted-stages/ms-2000-flat-top-xyz-automated-stage/
- https://www.asiimaging.com/products/stages/xy-inverted-stages/ms-2000-xyz-automated-stage/
- https://spectraservices.com/product/6-u220.html
- https://spectraservices.com/product/6-u220-u.html
- https://www.labx.com/item/olympus-ix-ulwcd-long-working-distance-condenser/DIS-41276-6-U220
- https://online.ogs.ny.gov/purchase/spg/pdfdocs/1260023072PL_OlympusAmerica.pdf
- https://krebsmicro.com/pdf/Olympus%20Price%20List_B.pdf
- https://www.tengrant.com/upLoad/file/20190331/IX73-IX83_system_chart.pdf
- https://www.wpiinc.com/var-3781-microelectrode-holder-mph6s
- https://wpiinc.com/products/var-3819-microelectrode-holder-mph3
- https://www.warneronline.com/q-series-holders-for-Warner-and-some-early-axon
- https://www.harvardapparatus.com/media/brochures/Warner_Microelectrode_Holders.pdf
- https://products.narishige-group.com/group1/HI-7/injection/english.html
- https://products.narishige-group.com/group1/HI-9/injection/english.html
- https://www.fishersci.pt/shop/products/grip-head-0/11886884
- https://www.eppendorf.com/product-media/doc/en/142967_Supplement-sheet/Eppendorf_Cell-Technology_Instructions-use_Universal-capillary-holder.pdf
- https://shop.fischerspindle.com/Collets/ER8/en
- https://www.freertool.com/products/9-pc-collet-set-7mm-5mm-er8-style-collet
- https://www.toolsengg.com/collets-64/er-collets/er-standard-collets/er8-standard-collets
- https://www.thorlabs.com/item/KB25_M
- https://www.thorlabs.com/thorproduct.cfm?partnumber=KB50/M
- https://www.thorlabs.com/kinematic-bases2
- https://cdn.meviy.misumi-ec.com/en_us-us/
- https://www.misumi.co.jp/english/news/press_240708
- https://www.misumi.co.jp/english/news/press_250512_3
- https://us.misumi-ec.com/pdf/fa/2010/p2319.pdf
- https://us.misumi-ec.com/vona2/detail/110302690740/
- https://us.misumi-ec.com/vona2/detail/110302691870/
- https://us.misumi-ec.com/vona2/detail/110302690310/
- https://it.misumi-ec.com/files/images/products/docs/nutsforaluminiumextrusions.pdf
- https://www.wpiinc.com/clientuploads/pdf/catalog/pages/capillaryglass.pdf
- https://wpiinc.com/products/var-1972-standard-glass-capillaries-2mm-od
- https://wpiinc.com/products/var-3709-thin-wall-glass-capillaries
- https://wpiinc.com/products/var-tw100-3-thin-wall-glass-capillaries-no-filament
- https://www.fishersci.com/shop/products/bor-glass-tubing-225-pk/NC9051667
- https://www.sutter.com/micropipette/glass-0-0
- https://www.autom8.com/shop/micropipette-fabrication/glass/borosilicate-glass1-5-x-0-86mm-x-10cm-250-pcs/
- https://products.narishige-group.com/group1/G-1_1.2_1.5_2_3/pipette/english.html
- https://www.tritechresearch.com/G-1.html
- https://www.idex-hs.com/store/product-detail/fep_tubing_1_16_od_x_030_id_natural_50ft/1520l
- https://www.idex-hs.com/store/fluidics/fluidic-connections/tubing/fluoropolymer-tubing/teflonr-fep-tubing.html
- https://www.idex-hs.com/store/product-detail/flangeless_fitting_short_peek_1_4_28_flat_bottom_for_1_16_od_natural_10_pack/xp-235x
- https://www.coleparmer.com/i/idex-flangeless-ferrule-blue-etfe-1-16-od-tubing-1-4-28-flat-bottom-10-pk/0193930
- https://www.idex-hs.com/store/products/fluidics/fluidic_connections/connectors/luer_adapters
- https://scipro.com/idex-fluidics-connectors-luer-adapters/
- https://docs.duet3d.com/Duet3D_hardware/Duet_3_family/Duet_3_Mainboard_6HC_Hardware_Overview
- https://www.duet3d.com/duet3mainboard6hc
- https://forum.duet3d.com/topic/28043/confused-about-duet3-boards-having-tmc2160-or-tmc5160
- https://www.aliexpress.com/item/1005001633960755.html
- https://biqu.equipment/products/tmc5160-pro-v1-0
- https://www.amazon.com/BIGTREETECH-TMC5160-Stepper-Drivers-heatsink/dp/B0B8HZXWPP
- https://dfh.fm/products/btt-ez5160-pro-stepper-motor-driver
- https://www.trinamic.com/products/modules/details/tmcm-3110/
- https://www.mouser.com/new/trinamic/trinamic-tmcm-3110-stepper-motor-drivers/
- https://www.analog.com/en/products/tmcm-3216.html
- https://www.ia.omron.com/product/item/2224/
- https://datasheet.octopart.com/EE-SX672-Omron-datasheet-134124.pdf
- https://industry.panasonic.com/global/en/products/fasys/sensor/micro/number/pm-t45
- https://industry.panasonic.com/global/en/products/fasys/sensor/micro/number/pm-l25
- https://omronfs.omron.com/en_US/ecb/products/pdf/en-d2f.pdf
- https://octopart.com/d2vw-5-1hs-omron-47505
- https://www.mouser.com/ProductDetail/MEAN-WELL/LRS-150-24?qs=vDxCgdWo2h%2Bym5KOpEI%2Bpw%3D%3D
- https://us.rs-online.com/product/mean-well/lrs-150-24/70696543/
- https://powersupplymall.com/products/mean-well-sdr-120-24-single-output-industrial-power-supply-120w-24v-din-rail
- https://us.rs-online.com/product/idec-corporation/xw1e-bv402m-r/70172752/
- https://www.newark.com/idec/xa1e-bv3u02-r/switch-emergency-stop-2nc-250vac/dp/05R0253
- https://www.tme.com/us/en-us/details/xa1e-bv3u02r/panel-mount-switches-standard-16mm/idec/
- https://www.ia.omron.com/products/family/3419/
- https://www.digikey.com/en/products/detail/omron-automation-and-safety/G9SE-201/7495167
- https://automation.omron.com/en/us/products/family/G9SE
- https://www.igus.com/product/series-E2i-15
- https://www.igus.com/product/series-E2-15
- https://www.tme.com/us/en-us/details/b15i.050.075.0/cable-chains/igus/

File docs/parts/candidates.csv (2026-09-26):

id | category | item | qty | requirement | candidate_1 | candidate_2 | candidate_3 | key_spec | approx_price | price_basis | source_urls | verified | notes
P01 | Actuator | Z stage (vertical, landing axis) | 1 | actuator stroke >=50 mm (tip travel 50 mm; model uses 80 mm catalogue stroke); ball screw lead 1 mm; no drop unpowered; compact width; repeatability <=10 um | THK KR20 LM Guide Actuator, lead 1: KR2001A-0080-P0-01A0 (precision) or KR2001A-0080-H0-01A0 (high-accuracy); 80 mm stroke, no cover | MISUMI LX20 lead 1 (LX2001P precision grade); stroke/motor bracket code to be configured on MISUMI site | Oriental Motor DRS2 42 mm guide type with electromagnetic brake and AZ absolute encoder (e.g. DRSM42RG-...AZMK family); exact PN (lead/stroke/brake) to configure | KR20: ball screw lead 1 or 6 mm, strokes 30/80/130 seen as stock PNs; grades normal/H/P. LX20: repeatability +-0.005 (high grade) / +-0.003 (precision). DRS2: repeatability +-0.01 rolled / +-0.003 ground; brake option | KR20: not found (used unit on eBay ~USD 108 + shipping); DRS2 with driver: not found | approx; USD eBay used only | https://catalog.orientalmotor.com/item/linear-actuators-linear-slides-only/thk-lm-guide-actuator-kr20/kr2001a-0080-h0-01a0 ; https://catalog.orientalmotor.com/item/linear-actuators-linear-slides-only/thk-lm-guide-actuator-kr20/kr2001a-0030-p0-01a0 ; https://www.thk.com/jp/en/products/lm_guide_actuator/selection/0008/ ; https://us.misumi-ec.com/pdf/fa/2014/P1_0417.pdf ; https://www.orientalmotor.com/linear-actuators/compact-linear-actuators-drs-series-absolute-encoder.html ; https://www.monotaro.com/p/1564/1826/ | PNs verified (Oriental Motor THK listing); KR20 numeric repeatability per grade UNVERIFIED (THK accuracy table exists but values not seen) | Lean KR2001A-0080-P0 (or H0). No 50 mm stock stroke seen -> use 80 mm (margin for touch-off/park). Lead 1 mm: back-drive torque ~0.4 mN.m, self-holding with motor detent. Check KR20 direct motor mount for NEMA17 (THK store lists KR20 Direct Motor Mount). Monotaro lists KR2001A semi-order items -> buyable in Japan.
P02 | Actuator | X stage (cantilevered, tip X) | 1 | actuator stroke >=100 mm (tip travel -15..+85 = 100 mm; model uses 110 mm catalogue stroke); lead 2 mm; light & stiff; ball screw | MISUMI LX26 lead 2, precision grade: LX2602P-...-150 (or -100); example real PN LX2602-B1-A2625-100 (high grade, 100 mm); motor bracket code to configure for NEMA17 | THK KR26 lead 2: KR2602A-0110-P0-01A0 (110 mm, precision) or KR2602A-0160-H0-01A0 | THK KR2001A-0130-H0/P0-01A0 (lead 1, 130 mm) if one actuator family preferred (slower: 1 mm lead) | LX2602/LX2605: strokes 100/150 available; repeatability +-0.005 (high) / +-0.003 (precision). KR26: lead 2, strokes 110/160/210 seen | LX26 base price JPY 43,000-66,600 (range across variants) | approx; JPY MISUMI search excerpt | https://us.misumi-ec.com/vona2/detail/110300075270/ ; https://in.misumi-ec.com/pdf/fa/2014/p1_421_001_p1_423.pdf ; https://www.radwell.com/en-US/Buy/MISUMI/MISUMI/LX2602-B1-A2625-100/ ; https://catalog.orientalmotor.com/item/linear-actuators-linear-slides-only/thk-lm-guide-actuator-kr26/kr2602a-0110-0-01a0 ; https://jp.misumi-ec.com/maker/misumi/mech/special/actuator_portal/lx/detail/ | LX26 repeatability & strokes: excerpt, one source (MISUMI PDF); KR26 PNs verified via Oriental listing; price unverified | Stroke exactly 100 leaves no margin to hard stops -> prefer 110 (KR26) or 150 (LX26). Cantilever: check moment rating (Mp/My) of carriage vs ~1.3 kg Z group at ~50-80 mm offset.
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

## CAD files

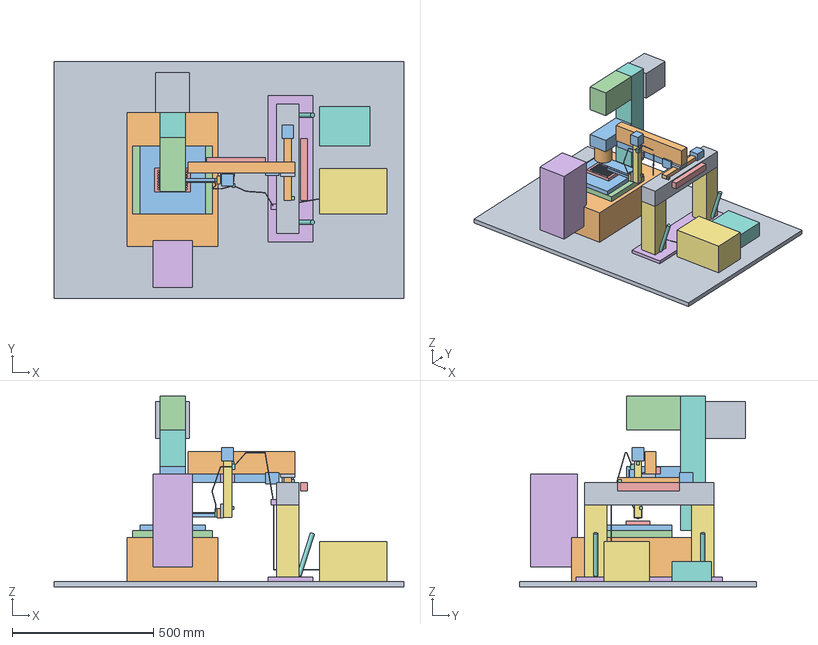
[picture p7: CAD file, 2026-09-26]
cad/out/assembly_WA_V45_IX-ULWCD.step
1240.0 x 840.0 x 676.0 mm
optical_table_patch
ix73_body_lower
ix73_stage
ix73_stage_support
ix73_objective_zone
ix73_obs_tube_eyepieces
ix73_stage_handle
ix73_illum_pillar
ix73_lamp_house
condenser_IX-ULWCD
condenser_carrier_arm
illum_arm_to_pillar
plate_96_SLAS
base_plate
post_0
post_brace_0
post_1
post_brace_1
y_beam
Y_actuator_body
Y_motor
Y_home_switch
Y_cable_chain
tubing_fixed_clamp
syringe_pump_existing
motion_controller_24V
Y_carriage
X_support_beam
X_actuator_body
X_motor
X_home_switch
X_cable_chain
X_carriage_bracket
Z_actuator_body
Z_motor
Z_home_switch_top
Z_reference_switch
tubing_clamp_Zbody
Z_carriage
breakaway_kinematic_mount
arm_thin
arm_deep
capillary_holder_collet
glass_capillary_OD1.0
tubing_head_0
tubing_head_1
tubing_head_2
tubing_head_3
tubing_head_4
tubing_loopZ_0
tubing_loopZ_1
tubing_loopZ_2
tubing_loopZ_3
tubing_loopZ_4
tubing_loopXY_0
tubing_loopXY_1
tubing_loopXY_2
tubing_loopXY_3
tubing_loopXY_4
tubing_to_pump_0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

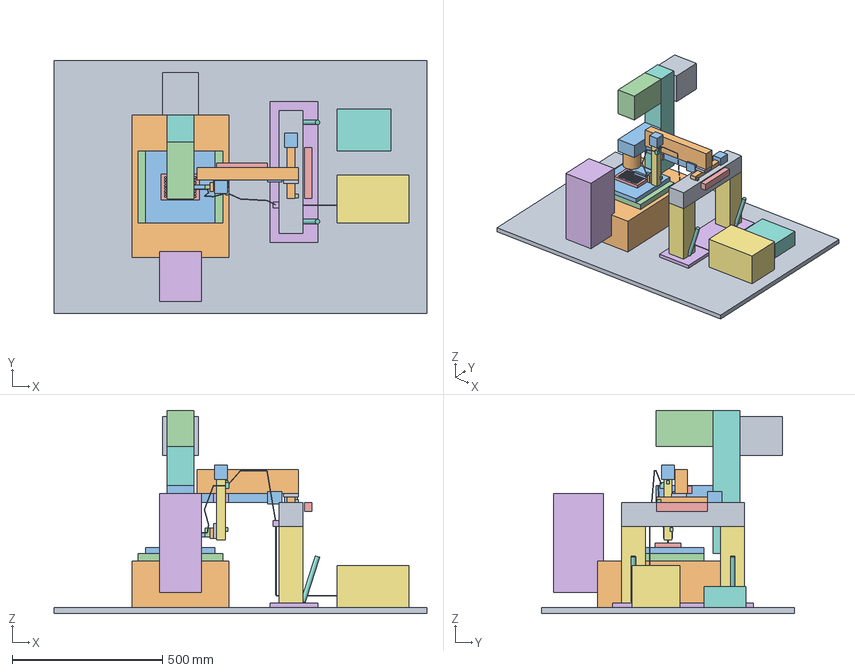
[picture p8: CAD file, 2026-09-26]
cad/out/assembly_WB_V30_IX-ULWCD.step
1240.0 x 840.0 x 676.0 mm
optical_table_patch
ix73_body_lower
ix73_stage
ix73_stage_support
ix73_objective_zone
ix73_obs_tube_eyepieces
ix73_stage_handle
ix73_illum_pillar
ix73_lamp_house
condenser_IX-ULWCD
condenser_carrier_arm
illum_arm_to_pillar
plate_96_SLAS
base_plate
post_0
post_brace_0
post_1
post_brace_1
y_beam
Y_actuator_body
Y_motor
Y_home_switch
Y_cable_chain
tubing_fixed_clamp
syringe_pump_existing
motion_controller_24V
Y_carriage
X_support_beam
X_actuator_body
X_motor
X_home_switch
X_cable_chain
X_carriage_bracket
Z_actuator_body
Z_motor
Z_home_switch_top
Z_reference_switch
tubing_clamp_Zbody
Z_carriage
breakaway_kinematic_mount
arm_thin
arm_deep
capillary_holder_collet
glass_capillary_OD1.0
tubing_head_0
tubing_head_1
tubing_head_2
tubing_head_3
tubing_head_4
tubing_loopZ_0
tubing_loopZ_1
tubing_loopZ_2
tubing_loopZ_3
tubing_loopZ_4
tubing_loopXY_0
tubing_loopXY_1
tubing_loopXY_2
tubing_loopXY_3
tubing_loopXY_4
tubing_to_pump_0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

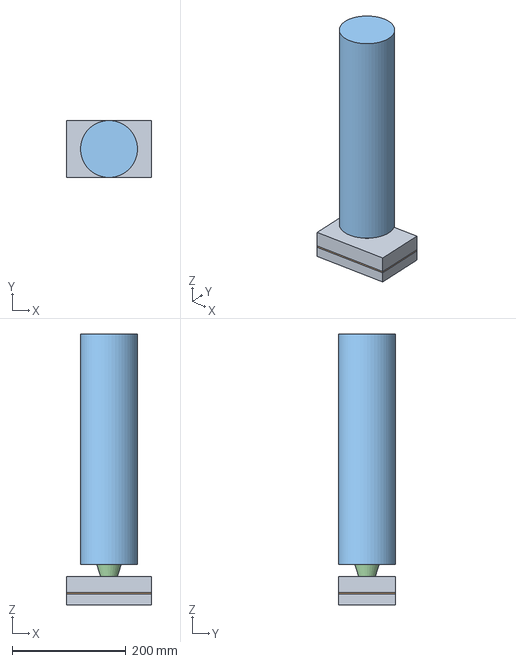
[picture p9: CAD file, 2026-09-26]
cad/out/zones_WA_IX-ULWCD.step
150.0 x 100.0 x 475.7 mm

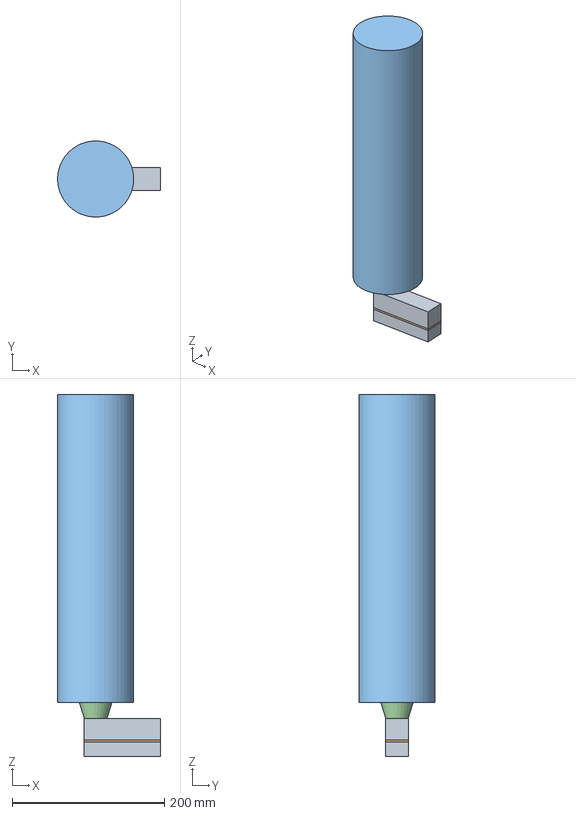
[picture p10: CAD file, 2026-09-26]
cad/out/zones_WB_IX-ULWCD.step
134.9 x 100.0 x 475.7 mm

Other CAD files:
cad/out/assembly_WA_R08_IX-ULWCD.step
cad/out/assembly_WB_R08_IX-ULWCD.step
cad/out/assembly_R08_IX-ULWCD.step
cad/out/assembly_V45_IX-ULWCD.step
cad/out/zones_IX-ULWCD.step
cad/out/assembly_WB_V20_IX-ULWCD.step
cad/out/assembly_WA_V00_IX-ULWCD.step
cad/out/assembly_WA_V30_IX-ULWCD.step
cad/out/assembly_WA_V20_IX-ULWCD.step
cad/out/assembly_V30_IX-ULWCD.step
cad/out/assembly_V00_IX-ULWCD.step

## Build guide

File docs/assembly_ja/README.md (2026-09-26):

# 組立手順書(日本語)

- `assembly_guide_ja.html` … 生成物(直接編集しない)
- `guide.src.html` … 本文テンプレート。`{{KEY}}` は `cad/keynums.py` の数値、`{{IMG:x.png}}` は画像。
- `build_guide.py` … テンプレート → HTML(画像を埋め込み、未実測の仮値一覧と変更履歴を自動挿入)
- `figures.py` … 実測箇所図(日本語フォント IPAex ゴシックが必要: `JP_FONT` か同じフォルダの `ipaexg.ttf`)
- `render_steps.js` … 3D ビューアから工程図を撮影

一括更新: `python tools/build_all.py`(3D 工程図も撮り直すなら `RENDER_JS=docs/assembly_ja/render_steps.js` と `CHROME`、`THREE_DIR` を設定)。

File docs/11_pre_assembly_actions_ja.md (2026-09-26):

<!-- GENERATED from docs/src/11_pre_assembly_actions_ja.md by cad/render_docs.py - edit the source, not this file -->
# 組立前にやること(IX73 外付けキャピラリピッカー)

この文書は、組立手順書(`docs/assembly_ja/assembly_guide_ja.html`)の**前段**にあたる作業リストです。手元の機材の確認、実測、試験、決定、発注、製作を、依存関係の順に並べています。組立工程そのもの(工程 1–10、立ち上げと校正)は手順書にあり、ここでは繰り返しません。

- 前提ワークフローは **W-B(暫定)** です。ステージが各ウェルを光軸へ運び、ピッカーは光軸付近だけを動きます(`docs/09_workflow_D1.md`)。
- 文中の数値は、現時点の `cad/params.py` から描画された文書(`docs/03`, `05`, `07`–`10`)からの引用です。この文書の数値は自動更新されません。`params.py` を更新したら、元の文書の数値と照合してください。
- 納期、価格、在庫はリポジトリに情報がありません。見積時に確認します。
- 部品の候補は `docs/12_parts_candidates.md`(元データ `docs/parts/candidates.csv`)の P-番号で参照します。候補は検索結果の抜粋に基づくもので、型番・価格・納期は見積時に確認します。
- 各項目の「担当: ___ / 時期: ___」は空欄のまま配っています。記入して使ってください。

記号: ☐ = 未完了(完了したら ☑ に書き換える)。項目 ID は M-/D- がリポジトリの ID です。I-(在庫確認)、T-(試験)、O-(発注)、F-(製作)、C-(最終チェック)はこの文書だけの番号です。

---

## まずこれだけ(最初の 8 件)

| 順 | ☐ | やること | これで決まる / 解除されること | 参照 |
|---|---|---|---|---|
| 1 | ☐ | 手元のコンデンサの型式を確認する(IX-ULWCD / IX2-LWUCD / IX2-MLWCD / その他)(I-1, M6) | IX-ULWCD を手配するかどうか(D2)。M8 と M18 を実施できるか | `05` M6, `02` |
| 2 | ☐ | 手元のステージの型式を確認する(IX3-SVR / IX3-SSU / 他社電動)(I-2) | 電動 XY ステージを新規に手配するか(D7)。IX3-SSU(76 × 52 mm)では 48/96 しか光軸に運べない | `09` |
| 3 | ☐ | 手元のポンプの型式、ポート、通信方式、**外部停止(インヒビット)入力の有無**を確認する(I-3, M17) | シリンジ容量、チューブ、D6 | `05` M17, `08` |
| 4 | ☐ | 凍結ゲートの実測のうち、今の機材で測れるものを測る: M1, M3, M4, M7, M10, M15 | 支柱高さ、架台位置、X 支持梁の余裕 | `05` |
| 5 | ☐ | 電動 XY ステージ(IX73 用、移動量 ≥ 99 × 63 mm)と IX-ULWCD(持っていない場合)の**見積と納期を問い合わせる**(O-1) | 長納期品の見通し。発注の時期 | `09`, `07` D2/D7 |
| 6 | ☐ | IX-ULWCD を手元に用意する(所有品、借用、または購入)。そのうえで M6(外径・外形)と M8(ピント状態の前玉高さ)を測る。ホルダーの試作品か購入品で M23(コレット先端 → ヘッド最上点の鉛直距離)も測る。V1 プレート Corning 7007 の実物で M19 も測る | 凍結ゲートの残り項目。アームの細い部分の長さ、コンデンサとの余裕 | `05` M6/M8 |
| 7 | ☐ | M18 照明試験を行う(T-1) | 96-well 用の傾き 8° のままでよいか、10–12° にするか(D3) | `05` M18, `02` |
| 8 | ☐ | 実測値を `cad/params.py` に入れ(状態を `PH` → `MEAS`)、全体を再計算して干渉結果を確認する(C-1 の先取り) | 凍結ゲートの通過判定。これ以前は製作・発注確定に進まない | `05` 冒頭, README |

---

## 凍結ゲート

> **凍結ゲート(10 項目): M1, M3, M4, M6, M7, M8, M10, M15, M19, M23**
>
> この 10 項目を実測して `cad/params.py` に入れ、再計算するまで、ブラケット形状、部品型番、加工図を確定しません(`05_measurement_checklist.md`、`07_assumptions_and_open_items.md`)。W-B では、選んだ電動 XY ステージの外形と移動量もあわせて記録します(`05` 冒頭、`09` 凍結ゲート表)。
>
> 現在のモデルのコンデンサ付近の余裕(安全高さで 4.83 mm)は、仮のコンデンサ外形(Ø80 mm)から出た値です。**設計根拠ではありません。**

注意:

- M8 は「実際に使うコンデンサ」を付けて測ります。IX-ULWCD を持っていない場合、M8 は IX-ULWCD が届く(または借りられる)まで測れません。つまり **IX-ULWCD の手配が凍結ゲートの前提**になります。D2 で照明支柱を倒す案を選ぶ場合は、代わりに M10 が主になります。
- M3 は `05` では「IX3-SVR を付けた状態」と書かれています。W-B で別の電動ステージを使う場合、そのステージの外形(メーカー外形図か実物)で M3 を取り直す必要があります。外形図で代用できるかは未確認です。

---

## 依存関係の図

```mermaid
flowchart TD
  I1["I-1 コンデンサ型式の確認"] --> D2["D2 コンデンサ方針"]
  I2["I-2 ステージ型式の確認"] --> D7["D7 電動XYステージ選定"]
  D1["D1 ワークフロー（暫定 W-B）"] --> D7
  I3["I-3 ポンプ型式の確認 / M17"] --> T2["T-2 ポンプ・チューブ乾式試験"]
  M10["M10 支柱を倒した外形"] --> D2
  D2 --> O3["O-3 IX-ULWCD 手配（未所有なら）"]
  O3 --> M68["M6 / M8 コンデンサ実測"]
  M68 --> T1["T-1 M18 照明試験"]
  T1 --> D3["D3 96-well 用の傾き"]
  D7 --> O2["O-2 電動XYステージ発注"]
  O2 --> M34["M3 / M4 ステージ外形・中心"]
  M1["M1 / M7 / M15 実測"] --> G[["凍結ゲート 通過判定"]]
  M34 --> G
  M68 --> G
  M10 --> G
  M121315["M12 / M13 / M15"] --> D4["D4 架台の左右"]
  D4 --> G
  G --> O4["O-4 直動ステージ・モーター発注確定"]
  D5["D5 Z軸の方式"] --> O4
  G --> F["F- 製作・加工"]
  D3 --> F6["F-6 角度ブロック"]
  I5["I-5 対象物サイズ / M19 プレート"] --> D6["D6 キャピラリ種類"]
  T2 --> D6
  D6 --> O5["O-5 キャピラリ発注"]
  D6 --> F7["F-7 コレットインサート"]
  M16["M16 定盤の穴ピッチ"] --> F1["F-1 ベース板"]
  G --> F1
  O4 --> O7["O-7 電装品発注"]
  F --> C["C- 組立前の最終チェック"]
  F6 --> C
  F7 --> C
  O5 --> C
  O7 --> C
```

図の読み方: 矢印の元が終わるまで、先の項目は確定できません。見積や問い合わせ(O-1)は、この図とは関係なく今すぐ始めて構いません。

---

## 1. 手元の確認・計測

### 1a. 手元にある機材の確認(在庫確認)

| ☐ | ID | 内容 | 理由(何が決まるか) | 前提 | 担当 / 時期 | 参照 |
|---|---|---|---|---|---|---|
| ☐ | I-1 | コンデンサの型式をすべて確認する(ラベル写真)。IX-ULWCD、IX2-LWUCD、IX2-MLWCD のどれがあるか | D2。IX2-LWUCD(WD 27 mm)と IX2-MLWCD(WD 45 mm)ではアームが吸引高さで当たる(モデル上)。IX-ULWCD(WD 73 mm)なら 96/96 | なし | 担当: ___ / 時期: ___ | `05` M6, `02` §Condenser |
| ☐ | I-2 | ステージの型式を確認する(IX3-SVR 手動 114 × 75 mm か、IX3-SSU 電動 76 × 52 mm か、他社電動か)。ステージインサートとプレートホルダーの種類も記録 | D7。W-B の自動化には移動量 ≥ 99 × 63 mm の電動ステージが必要 | なし | 担当: ___ / 時期: ___ | `09` §Stage requirement |
| ☐ | I-3 | ポンプの型式(`source_manifest` では Harvard Pump 11 Elite / PHD ULTRA / Tecan Cavro Centris/XLP を候補として挙げているが、実機は未確認)、外形、チューブポート、通信(RS-232/USB)、使えるシリンジ容量 | M17。シリンジ容量(例 25–100 µL)、チューブ、D6 | なし | 担当: ___ / 時期: ___ | `05` M17, `08`, `source_manifest` 項目 5 |
| ☐ | I-4 | V1 は Corning 7007 に固定。ほかに使いたいプレートがあれば種類と型番を挙げる(試験扱い)。蓋を置く場所(M21) | M19, M21。角度ブロックの組合せ、安全高さ | なし | 担当: ___ / 時期: ___ | `05` M19/M21, `10` |
| ☐ | I-5 | 扱う対象物のサイズ分布(スフェロイド、粒子、ビーズ等)と、柔らかさ | D6。100 µm–1 mm のどのクラスを揃えるか | なし | 担当: ___ / 時期: ___ | `08` §Still to confirm |
| ☐ | I-6 | カメラ、サイドポート、接眼部の構成(左右どちらに何が付くか) | M12, D4 | なし | 担当: ___ / 時期: ___ | `05` M12 |
| ☐ | I-7 | 除振台の有無と使い方(浮上させて使うか)、PC とコントローラの置き場所 | M20, M22。静定時間、ケーブル長 | なし | 担当: ___ / 時期: ___ | `05` M20/M22 |

### 1b. 実測(M 項目)

共通のやり方(`05` 冒頭より): 原点は光軸とステージインサート上面の交点、+X は操作者の右、+Y は奥、+Z は上。**各測定は定規を写し込んで写真を撮る**。値は `cad/params.py` に入れ、状態を `PH` から `MEAS` に変える。

用意する道具(目安): 巻尺、直尺(300 mm 以上)、デプスバー付きノギス、ハイトゲージ(あれば)、スコヤ、水準器、カメラ、マスキングテープ、Ø10 mm 程度の棒(M18 用)。

優先度は `05` のとおり: A = 実現性を決める、B = ブラケット設計の前に必要、C = あるとよい。**太字の ID が凍結ゲート項目**です。

| ☐ | ID | 優先 | 測るもの | 測り方・道具 | 決まること(解除される項目) | 前提 | 担当 / 時期 | 参照 |
|---|---|---|---|---|---|---|---|---|
| ☐ | **M1** | A | 定盤面 → ステージインサート上面(プレートを置く面) | ハイトゲージか直尺で、ステージ中央付近を 3 点。現在のモデル値 200 mm は仮値 | 支柱と梁の高さ(F-2)。架台全体 | なし | 担当: ___ / 時期: ___ | `05`, 手順書「組立前の実測」 |
| ☐ | M2 | A | 定盤 → 実際に使うプレートの上面。プレートを置いたときの A1 の角の位置 | M1 と同じ道具。プレートを置いて上面を測り、A1 の向きを写真で記録 | ウェル座標、安全高さ(C-1 の再計算) | I-4 | 担当: ___ / 時期: ___ | `05` |
| ☐ | **M3** | A | ステージ外形、インサートの開口、プレート上面より上に出るクリップ・ホルダー | 真上から写真、突出高さはノギス。W-B で電動ステージに替える場合は、そのステージで取り直す | 吸引高さでのアームとの余裕、動くプレートとの余裕 | I-2(W-B では O-2 か外形図) | 担当: ___ / 時期: ___ | `05`, `09` 凍結ゲート |
| ☐ | **M4** | A | 「基準位置」でのステージ中心と光軸のずれ。ステージを固定できるか | 低倍で視野中心に印を合わせ、ステージ目盛りを記録 | D1(W-B でのステージ移動範囲の使い方) | I-2 | 担当: ___ / 時期: ___ | `05`, 手順書 |
| ☐ | M5 | B | 光軸から本体の前・後・左・右面までの距離 | 巻尺・直尺。光軸位置は M4 で付けた印を基準にする | 架台の位置 | M4 | 担当: ___ / 時期: ___ | `05` |
| ☐ | **M6** | A | 実際に使うコンデンサの型式と外径(外形) | 型式ラベル写真、ノギスで外径。現在のモデル値 Ø80 mm は仮値 | アームの細い部分の長さ(W-B 現在 60 mm)、コンデンサ付近の全余裕、D2 | I-1(IX-ULWCD が手元にあること) | 担当: ___ / 時期: ___ | `05`, `02` |
| ☐ | **M7** | A | コンデンサ保持アーム: 幅、最下点、光軸から左右面までの距離 | 正面から幅、定盤から最下点の高さ。現在のモデル値 ±45 mm は仮値 | X 支持梁との余裕(モデルでは 5 mm) | なし | 担当: ___ / 時期: ___ | `05` |
| ☐ | **M8** | A | 4× と 10× でピントを合わせた状態の、プレート上面 → コンデンサ前玉(下端)の高さ | 実際の観察状態のまま直尺・ノギスで。WD 73 mm(IX-ULWCD)はメーカー値だが、実際の高さは数 mm 違いうる | コンデンサ下の余裕(最も効く値) | M6、IX-ULWCD が手元にあること(O-3) | 担当: ___ / 時期: ___ | `05`, `07` 前提 4 |
| ☐ | M9 | B | 照明支柱の位置・断面・高さ、ランプハウスの外形 | 巻尺・直尺、側面写真 | 後方の余裕 | なし | 担当: ___ / 時期: ___ | `05` |
| ☐ | **M10** | A | 照明支柱を後ろへ倒したときの角度と外形 | 倒した状態で側面から写真、後方への張り出しを測る。倒す操作は取扱説明書と装置管理者の了解のもとで行う | D2 の代替案(コンデンサなしで運用)の成否 | なし | 担当: ___ / 時期: ___ | `05`, `03` §8 |
| ☐ | M11 | B | コンデンサを最上位置にしたときのプレート上の空き高さ | 直尺 | キャピラリ交換位置 | I-1 | 担当: ___ / 時期: ___ | `05` |
| ☐ | M12 | B | 観察鏡筒・接眼部の外形(前)、左右のサイドポートとカメラ | 巻尺、写真 | 前・横に干渉がないことの確認、D4 | I-6 | 担当: ___ / 時期: ___ | `05` |
| ☐ | M13 | B | IX3-SVR ハンドルの位置と振り回し範囲(右側)、左右の焦点ノブの位置 | 巻尺、写真。ハンドルを端まで回して範囲を確認 | 架台位置、手が届くか、D4 | I-2 | 担当: ___ / 時期: ___ | `05` |
| ☐ | M14 | B | ステージ下の対物レンズ・レボルバの最高点(最も長い対物で) | デプスバー付きノギスか直尺で、ステージ上面から下向きに | Z 下限の安全確認 | なし | 担当: ___ / 時期: ___ | `05` |
| ☐ | **M15** | A | 本体右側面から定盤端までの空き(X)、奥行き(Y)、他の機器(インキュベータ、コントローラ、PC) | 巻尺。他の機器の位置も図にする。W-B の架台は光軸から +443 mm 程度まで使う(モデル値) | 架台を置けるか。D4 | なし | 担当: ___ / 時期: ___ | `05`, `07` 前提 8 |
| ☐ | M16 | B | 定盤の穴ピッチ(M6/25 mm か ¼-20/1")、IX73 の脚に対する穴の位置 | ボルトを 1 本ねじ込んで規格を確認、穴位置を巻尺で | ベース板の長穴配置(F-1) | なし | 担当: ___ / 時期: ___ | `05`, `03` §9 |
| ☐ | M17 | A | ポンプの外形、チューブポート、制御方式、外部停止(インヒビット)入力の有無 | I-3 と同時に。データシートも入手 | ポンプ位置、流路長、チューブ(O-6) | I-3 | 担当: ___ / 時期: ___ | `05` |
| ☐ | **M19** | A | V1 プレート Corning 7007 の実物のウェル縁径、深さ、蓋なし高さ、A1 の位置(ほかのプレートは試験扱いで記録のみ) | 購入ロットをノギスとデプスゲージで。メーカー図面と比べる | V1 の受け入れ条件(目標が底中心から 0.5 mm 以内)、安全高さの下限 | I-4 | 担当: ___ / 時期: ___ | `05`, `10` |
| ☐ | M20 | C | 振動: 除振台オン/オフ、定盤か実験台か | 状態を記録するだけでよい | 吸引前の静定時間 | I-7 | 担当: ___ / 時期: ___ | `05` |
| ☐ | M21 | B | 作業中にプレートの蓋を置く場所 | 運用を決めて記録。モデルは蓋なしを前提(Corning 7007 は蓋込み 16.5 mm) | ワークフロー | I-4 | 担当: ___ / 時期: ___ | `05`, 手順書「安全の決まりごと」 |
| ☐ | M22 | C | PC・コントローラまでのケーブル経路 | 巻尺で経路長 | ケーブル長(O-7) | I-7 | 担当: ___ / 時期: ___ | `05` |

M18 は試験なので次の節にあります。

---

## 2. 試験

| ☐ | ID | 内容 | 理由(何が決まるか) | 前提 | 担当 / 時期 | 参照 |
|---|---|---|---|---|---|---|
| ☐ | T-1(M18) | **照明試験**。Ø10 mm 程度の棒をピントの 30–45 mm 上に置き、光軸から 0 / 4 / 8 mm ずらす。4× と 10×、開口絞りを開いた状態と絞った状態で像を撮る | D3(96-well 用の傾きを 8° のままにするか、10–12° にするか)。モデルの遮光率(8° で NA 0.3 のとき 28 %)は解析的な推定で、光学シミュレーションではない | 使う予定のコンデンサ(IX-ULWCD)が付いていること。未所有なら O-3 のあと。所有コンデンサで先に行う場合は結果を参考扱いにする | 担当: ___ / 時期: ___ | `05` M18, `02` |
| ☐ | T-2 | **ポンプ・チューブ乾式試験**(卓上、ピッカーなし)。既存ポンプ + PTFE/FEP 1/16" チューブ(約 1.2 m)+ キャピラリで、液を満たし、気泡抜け、漏れ、1 回あたりの吸引量(S: 約 0.5 µL、M: 約 1.1 µL、L: 約 2.0 µL)の再現性を確認する。曲げ半径 25 mm のループを作って影響を見る | チューブの種類・内径・長さ(O-6)、シリンジ容量、D6。試験の方法と合否基準はリポジトリにないので、担当者が決めて記録する | I-3 / M17。チューブとキャピラリの手持ち品(なければ少量を先に購入) | 担当: ___ / 時期: ___ | `08` §Proposed set, `03` §7, `07` 前提 11 |
| ☐ | T-3 | **ステージ到達確認**。今のステージで A1、A12、H1、H12 を光軸に運べるか、端で何 mm 余るかを記録する | M2/M4 の確認、D1 と D7 の判断材料。IX3-SSU なら 48/96 しか運べない(モデル) | I-2, M4 | 担当: ___ / 時期: ___ | `09` |
| ☐ | T-4 | (任意・提案)**手持ちの吸引試験**。架台なしで、キャピラリを手で保持してポンプで吸引し、クラスごとに吸引できるか、対象が壊れないかを見る | D6(内径 ≈ 物体径の 1.3–3 倍という比率は提案で、出典はない。実物で確認が必要) | T-2, I-5, 各クラスのキャピラリ | 担当: ___ / 時期: ___ | `08` §Still to confirm |

---

## 3. 決定

決定者はユーザー(`07` の「Open decisions (owner: user)」)。決めたら、この表と `07` の両方に結果と日付を残します。

| ☐ | ID | 問い | 選択肢 | 必要な情報(前提) | 影響 | 担当 / 期限 | 参照 |
|---|---|---|---|---|---|---|---|
| ☐ | **D1**(暫定: **W-B**) | 「全 96 ウェルで、IX73 で見ながら吸引・吐出する」必要があるか。対象が光軸近くの数ウェルだけで、吐出は見えなくてよいなら W-A も成り立つ。吐出先は同じプレートか、別プレートか(別プレートなら W-C、未モデル化) | W-B(ステージがウェルを光軸へ運ぶ、96/96 観察)/ W-A(ステージ固定、観察は 1 ウェル)| I-2, M4, T-3, D7 の見積(予算) | ピッカーの移動量(W-B: 100 × 30 × 50 mm、W-A: 150 × 100 × 50 mm)、アーム長(115 / 175 mm)、電動ステージの要否 | 担当: ___ / 期限: ___ | `09` |
| ☐ | D2 | ピッキング中のコンデンサをどうするか | IX-ULWCD(所有 / 借用 / 購入)/ 照明支柱を後ろへ倒し、架台側に LED リング照明 | I-1, M6, M8, M10, T-1。吸引中にケーラー明視野が要るか | ドッグレッグアームの要否、O-3 | 担当: ___ / 期限: ___ | `07`, `03` §8 |
| ☐ | D3 | 96-well での最終的な傾き | 8°(現行)/ 10–12°(T-1 の結果次第)。OD 1.0 mm でウェル底中心に届くのは 14.8° まで、OD 2.0 mm では 12.3° まで | T-1, D2, D6 | 角度ブロック(F-6)の角度、ホルダー座面 | 担当: ___ / 期限: ___ | `07` D3, `08`, `10` |
| ☐ | D4 | 架台を置く側 | 右(既定)/ 左(鏡像) | M12, M13, M15(あわせて M5, M9) | 架台位置、ベース板(F-1) | 担当: ___ / 期限: ___ | `07` D4 |
| ☐ | D5 | Z 軸の方式 | オープンループのボールねじ(リード 1 mm)/ クローズドループ・アブソリュート(DRS2 級)+ ブレーキ | 予算、原点復帰の方針。Z 可動部が約 0.5 kg を超えるか、リード 2 mm 以上を選ぶ場合はブレーキ付きを検討(`03` §5) | O-4、コントローラ構成(O-7) | 担当: ___ / 期限: ___ | `07` D5, `03` §5, `04` |
| ☐ | D6 | 揃えるキャピラリのクラス | S / M / L(OD 1.0 / 1.5 / 2.0)と、1 mm 級用の薄肉 L′(2.00 / 1.56)/ クラスを減らす | I-5, T-2, T-4、薄肉 2.00/1.56 の国内入手性、M17(シリンジ) | コレットインサート(F-7)、キャピラリ発注(O-5)、シリンジ容量 | 担当: ___ / 期限: ___ | `07` D6, `08` |
| ☐ | D7 | W-B 用の電動 XY ステージ | 120 × 80 mm 級の IX73 用電動ステージ(`source_manifest` S15 に記載の製品群)/ 当面は IX3-SVR で半自動運用。IX3-SSU(76 × 52 mm)は不足 | D1、移動量 ≥ 99 × 63 mm、IX73 への取付可否、プレートホルダー、コントローラと PC の接続、外形(凍結ゲート用)、耐荷重、速度、価格、納期 | 費用、制御統合、M3 の取り直し | 担当: ___ / 期限: ___ | `07` D7, `09` |

決める順番の目安: D1 → D7 → D2 → D3 → D4 → D5 → D6。D5 と D6 は他と並行して進められます。

---

## 4. 発注

長納期になりそうな品から並べています。**実際の納期はリポジトリに情報がなく、未確認です。** 見積時に必ず確認してください。部品候補は `docs/12_parts_candidates.md` の P-番号です。

| ☐ | ID | 品目(カテゴリ) | 条件(リポジトリの値) | 前提 | 納期リスク | 担当 / 時期 | 参照 |
|---|---|---|---|---|---|---|---|
| ☐ | O-1 | **見積・納期の問い合わせ**(発注ではない): 電動 XY ステージ、IX-ULWCD、直動ステージ 3 軸、薄肉キャピラリ | 下記 O-2〜O-5 の条件で | なし。今すぐ始めてよい | – | 担当: ___ / 時期: ___ | この表 |
| ☐ | O-2 | **電動 XY ステージ(IX73 用)** P07, P08 | 移動量 ≥ 99 × 63 mm(120 × 80 mm 級)。**IX3-SSU は不可**(76 × 52 mm、48/96)。プレートだけを載せる | D1, D7。IX73 への取付とインサートの互換を販売元に確認 | 高(他社製・取付アダプタ・コントローラ込みの可能性。未確認) | 担当: ___ / 時期: ___ | `09`, `07` D7 |
| ☐ | O-3 | **IX-ULWCD コンデンサ**(未所有の場合のみ)P09 | NA 0.3、WD 73 mm(販売店情報。メーカーに確認、`source_manifest` S04) | I-1, D2。購入前に借用で M6/M8/T-1 を済ませられるか相談 | 高(未確認) | 担当: ___ / 時期: ___ | `02`, `source_manifest` S04 |
| ☐ | O-4 | **直動ステージ X / Y / Z + モーター(NEMA17)× 3** P01–P06 | W-B: X ≥ 100 mm、Y ≥ 30 mm、Z 50 mm(Z はリード 1 mm ボールねじ)。幅 20–26 mm 級。X と Z は工業用コンパクト型(A 案)、Y は A か B。概算は 1 軸 5–12 万円程度(`04`、未検証) | **見積は今、発注確定は凍結ゲート後**(`07`: 型番は凍結前に確定しない)。D1, D5 | 中〜高(未確認)。`04` では A/B が長納期なら C 案(自作)を代替に挙げている | 担当: ___ / 時期: ___ | `03` §3, `04`, `07` |
| ☐ | O-5 | **ガラスキャピラリ** P21–P24 | D6 で決めたクラス: OD/ID 1.0/0.58、1.5/0.84(または 0.86)、2.0/1.12、薄肉 2.00/1.56(フィラメントなし) | D6。T-4 用に少量を先に買うのは可 | 薄肉 2.00/1.56 は国内の入手性・価格が未確認 | 担当: ___ / 時期: ___ | `08` |
| ☐ | O-6 | チューブ・継手・クランプ類 P25–P27 | PTFE/FEP 1/16" OD、約 1.2 m、曲げ半径 ≥ 25 mm(選んだチューブで要確認)。内径と長さはポンプと死容積で決める | M17, T-2 | 低(未確認) | 担当: ___ / 時期: ___ | `03` §7, `07` |
| ☐ | O-7 | 電装品 P28–P36 | 24 V DC 電源(約 150 W、ヒューズ付き)、モーションコントローラ(PC 接続、G-code、SPI、NC 入力 ≥ 6)、TMC5160 級ドライバ × 3、NC 原点スイッチ × 3、非常停止 + 接触器(モーター電源のみ遮断)、シールド付きモーターケーブル、ケーブルチェーン | O-4(モーター電流)、D5、M22(ケーブル長)。`07` では電源容量・コネクタ・基板は未確定 | 低〜中(未確認) | 担当: ___ / 時期: ___ | `06`, `07` |
| ☐ | O-8 | シリンジ(ポンプ用) | 分解能で選ぶ。例 25–100 µL(`08`) | M17, D6, T-2 | 低(未確認) | 担当: ___ / 時期: ___ | `08` |
| ☐ | O-9 | 架台の材料(アルミ 15 mm 板、80 × 80 角材 2 本 + Y 梁、40 × 80 以上の X 支持梁、ブレース、ボルト) | 断面は外形レベルの値。高さ(M1)と剛性の確認後に確定 | 凍結ゲート, M16, D4 | 低(未確認) | 担当: ___ / 時期: ___ | `03` §2, `07` |

---

## 5. 製作・加工

> **凍結ゲートを通過するまで、ここの加工は始めない。** 図面は描き始めてよいが、寸法は仮のまま扱う。

| ☐ | ID | 内容 | 理由(何が決まるか) | 前提 | 担当 / 時期 | 参照 |
|---|---|---|---|---|---|---|
| ☐ | F-0 | 凍結ゲートの実測値で `cad/params.py` を更新し、再計算した寸法から加工図を起こす | すべての製作物の寸法の根拠 | 凍結ゲート, C-1 | 担当: ___ / 時期: ___ | `05`, README §Rebuild |
| ☐ | F-1 | **ベース板**(Al 15 mm)。定盤の穴に合わせた長穴で X/Y ±15 mm、ヨー ±2°、ボルト 6 本 | 架台位置の調整幅 | 凍結ゲート, M16, D4 | 担当: ___ / 時期: ___ | `03` §9 |
| ☐ | F-2 | 支柱の切断と、梁の高さ調整部(縦長穴 + ジャッキボルト、±20 mm) | 梁の高さを実際のステージ高さに合わせる | M1, O-9 | 担当: ___ / 時期: ___ | `03` §9 |
| ☐ | F-3 | **ブラケット類**: X 支持梁の取付、X キャリッジ → Z、原点スイッチ、チューブクランプ #1/#2、ケーブルチェーン | 軸の積み上げ | 凍結ゲート、O-4 の実部品寸法(型番確定後) | 担当: ___ / 時期: ___ | `03` §2/§7 |
| ☐ | F-4 | **ドッグレッグアーム**。細い部分 12 × 12 mm、W-B の現行値は全長 115 mm・細い部分 60 mm。チューブを沿わせる側面の溝 | コンデンサ下の余裕。長さと厚みは M6–M8 で変わる | M6, M7, M8, D2 | 担当: ___ / 時期: ___ | `07` 未確定項目, `03` §7 |
| ☐ | F-5 | キネマティックマウント(3 球 + 磁石予圧、衝突で外れる) | 衝突時の保護、付け直しの再現性(数 µm は典型値で未検証) | F-4 | 担当: ___ / 時期: ___ | `02` 項目 10 |
| ☐ | F-6 | **角度ブロック 8° / 20° / 30°**(45° は作らない)。ピン 2 本 + ねじ 1 本、角度を刻印。どのブロックでも先端がZキャリッジに対して同じ公称点(±1 mm)に来る形状 | プレート形式ごとの角度。現行の推奨: 96-well 8°、48-well 8°、24-well 20°、12-well 30°(20° を予備)、6-well 30° | D3, M19, F-5。コンデンサとの余裕は M6/M8 後に再計算 | 担当: ___ / 時期: ___ | `10` |
| ☐ | F-7 | **コレットホルダーとインサート**(OD 1.0 / 1.5 / 2.0、Ø10 × 14 mm 外形)。深さストップ、端面の O リングシール、液ポート | クラスごとの保持。2.0 mm 用に Ø12 が必要なら `HOLDER_D = 12` で解析をやり直す | D6, O-5(実物の外径で合わせる), O-6(ポート) | 担当: ___ / 時期: ___ | `03` §6, `08` |
| ☐ | F-8 | 図面の相互確認(作図者以外の 1 名) | 仮値のまま寸法が残っていないか | F-1〜F-7 の図面 | 担当: ___ / 時期: ___ | `07` |

---

## 6. 組立前の最終チェック

| ☐ | ID | 内容 | 理由 | 前提 | 担当 / 時期 | 参照 |
|---|---|---|---|---|---|---|
| ☐ | C-1 | 凍結ゲートの 10 項目がすべて `MEAS` になっていることを確認し、`python tools/build_all.py` を **`--fast` なしで**実行する(干渉スイープを含む) | 実測値での干渉結果を得る | 凍結ゲートの実測 | 担当: ___ / 時期: ___ | README §Rebuild |
| ☐ | C-2 | 再計算結果を確認する: 吸引高さ・安全高さで 96/96 が干渉なし、ステージ移動の角 9/9 が干渉なし、コンデンサとの最小余裕。判定基準は下の「確認中の食い違い」1 を参照 | 実機で当たらないことの確認 | C-1 | 担当: ___ / 時期: ___ | `09`, `10`, `generated_analysis_tables.md` |
| ☐ | C-3 | 残っている仮値(`PH`)の一覧を見て、残してよいものか確認する。現在は 19 件(手順書の「まだ仮の値」一覧) | 見落としの防止 | C-1 | 担当: ___ / 時期: ___ | 下の付録, 手順書 |
| ☐ | C-4 | 購入品の受入確認: ストローク、リード、モーター、スイッチが NC か、ケーブル長 | 発注どおりか | O-2〜O-9 | 担当: ___ / 時期: ___ | この文書 §4 |
| ☐ | C-5 | 製作品の寸法確認(特にアームの厚み、角度ブロックの角度、コレット径) | 図面どおりか | F-1〜F-7 | 担当: ___ / 時期: ___ | この文書 §5 |
| ☐ | C-6 | 顕微鏡側の準備: 電動ステージ取付済みで A1〜H12 を光軸に運べる、使うコンデンサが付いている | W-B の前提 | O-2, O-3 | 担当: ___ / 時期: ___ | `09` |
| ☐ | C-7 | 右側(または左側、D4)の定盤上を片付け、M15 の範囲と定盤の穴が使えることを確認。ポンプ・コントローラ・PC の置き場所を決める | 架台を置く場所 | D4, M15, M22 | 担当: ___ / 時期: ___ | `05` |
| ☐ | C-8 | 安全の準備: 非常停止の配線計画、Z の原点がコンデンサ下の基準スイッチ(1 個)であること、非常停止でポンプと電動ステージも止まること、Z が電源断で落ちないことを組立時に確認する段取り | 手順書「安全の決まりごと」の前提 | O-7 | 担当: ___ / 時期: ___ | `06`, 手順書 |
| ☐ | C-9 | T-2 の結果をもとにチューブ・シリンジ・液を準備。キャピラリは各クラスを予備込みで用意 | 組立工程 9–10 ですぐ使う | T-2, O-5, O-6, O-8 | 担当: ___ / 時期: ___ | `08` |
| ☐ | C-10 | 最新の組立手順書を生成して関係者で読み合わせる。顕微鏡の管理者に作業日と装置を止める時間を伝える | 作業当日の段取り | C-1 | 担当: ___ / 時期: ___ | 手順書 |

---

## 付録: `cad/params.py` の仮値(PH)と対応する実測

| パラメータ | いまの値 | 対応する実測 |
|---|---|---|
| `STAGE_TOP_ABOVE_TABLE` | 200 mm | **M1** |
| `COND_FRONT_Z_MEAS`(コンデンサ前玉の高さ、未入力なら WD から推定) | 76.05 mm(推定) | **M8** |
| `HEAD_TOP_FROM_NOSE_MEAS`(コレット先端 → ヘッド最上点の鉛直距離。未入力なら `HOLDER_AXIAL_LEN` などから計算) | 22.2 mm(計算値) | **M23** |
| `STAGE_T`(ステージ板厚) | 20 mm | M3 |
| `BODY_Y_FRONT` | −235 mm | M5 |
| `STAGE_CENTER_Y` | 0 mm | **M4** |
| `PILLAR_W`, `PILLAR_Y0`, `PILLAR_Y1` | 90 / 150 / 240 mm | M9 |
| `COND_ARM_W` | 90 mm | **M7** |
| `COND_D` | 80 mm | **M6** |
| `COND_BODY_H`(コンデンサ本体高さ) | 70 mm | M6 |
| `OBS_TUBE_BOX` | 箱形状 | M12 |
| `STAGE_HANDLE` | 箱形状 | M13 |
| `OBJECTIVE_ZONE` | r 45 mm | M14 |

M8(コンデンサ前玉の実高さ)は、`params.py` ではメーカーの WD から計算しているため PH としては数えられていません。M10(支柱を倒した外形)と M17(ポンプとその停止入力)に対応するパラメータは `params.py` にありません。どちらも凍結ゲートや発注に効くので、測った値はこの文書か `05` に記録してください。

---

自動集計した最新の仮値一覧は、組立手順書の「まだ決まっていないこと」にあります(`cad/keynums.py` の `placeholders()`)。

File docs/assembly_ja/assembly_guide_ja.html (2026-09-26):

picker_ / 第1段階(配置検討)更新: 2026-09-26 · c5b5466未実測の仮値: 19 件前提ワークフロー: W-B(ステージが各ウェルを光軸へ運ぶ)数値は cad/params.py から自動生成

# IX73 キャピラリピッカー 組立手順書

IX73 の右側に独立した架台を置き、XYZ ピッカーを組み立てて調整するまでの流れを、図と文章で示します。現時点の部品は外形だけの概念モデルで、型番は決まっていません。赤い【要実測】の値を測って入力するまで、ブラケット設計や部品発注に進まないでください。

その工程で取り付ける部品(図中のオレンジ) 要実測 実機で測る値 未確定 部品・寸法がまだ決まっていない

## 全体像

ピッカーは顕微鏡に一切触れません。光学定盤にボルト留めした架台(ベース板、支柱 2 本、Y 梁)に、Y → X → Z の順で直動ステージを積みます。Z ステージの先端から薄い「ドッグレッグアーム」をコンデンサの下へ差し込み、垂直から 8° 傾けたガラスキャピラリを保持します。

ウェルを選ぶのは顕微鏡ステージの役目です。ステージが対象ウェルを光軸へ運び、ピッカーは光軸付近だけを動きます。そのためピッカーの移動量は X 100 × Y 30 × Z 50 mm で足ります。X のうち +側は、キャピラリ交換のための待避位置として使います。

IX73 と右側のピッカー架台の全体図

全体図(W-B)。灰色は IX73 の仮外形、紫はコンデンサ(IX-ULWCD)、濃い青は架台と直動ステージ、緑はヘッド、黄はチューブ。

流体経路と動作系の機能図

流体経路(既存のシリンジポンプ → チューブ → キャピラリ)と動作系(PC → コントローラ → XYZ)は機械的に独立しており、ホルダーだけで結合します。

## 組立前の実測

凍結条件。次の 10 項目(M1, M3, M4, M6, M7, M8, M10, M15, M19, M23)を測り、cad/params.py に入れて再計算するまで、寸法を確定しません。現在のモデルでコンデンサ付近の余裕は約 4.83 mm ですが、これは仮の外形から出た数字です。

実測箇所を赤で示した正面図と側面図

赤が実測箇所。灰色の IX73 は仮の外形で、実寸ではありません。

ID | 測るもの | 測り方 | 何が決まるか | 現在のモデル値
M1 | 定盤面 → ステージ上面(プレートを置く面) | ハイトゲージか直尺で、ステージ中央付近の 3 点を測る | 支柱と梁の高さ | 200 mm(仮)
M3 | ステージ外形、プレートホルダー、クリップ類のプレート上面からの突出 | 上から撮影し、ノギスで突出高さを測る | アームとプレート周辺の余裕 | 232 × 240 mm(平ステージの仕様値)
M4 | ステージ中心と光軸のずれ、ステージ固定の可否 | 低倍で視野中心に印を合わせ、ステージ目盛りを記録する | ステージの移動範囲の使い方 | 中心一致を仮定
M6 | 実際に使うコンデンサの型式と外径 | 型式ラベルを確認し、ノギスで外径を測る | アームの薄い部分の長さ(現在 60 mm) | Ø80 mm(仮)
M7 | コンデンサ保持アームの幅と最下点 | 正面から幅を、定盤から最下点の高さを測る | X 支持梁との干渉 | 幅 90 mm(仮)
M8 | ピントを合わせた状態での、プレート上面 → コンデンサ下端の距離 | 4× と 10× で、実際の観察状態のまま測る | コンデンサ下の余裕(最も効く値) | WD 73 mm からの推定
M10 | 照明支柱を後ろへ倒したときの外形 | 倒した状態で側面から撮影し、後方への張り出しを測る | コンデンサなしで運用する場合の代替案 | 仮
M15 | IX73 本体の右側面から定盤端までの空き | 巻尺で奥行き方向にも測る。他の機器の位置も記録する | 架台を置けるか(必要: 光軸から +458 mm 程度) | 十分と仮定
M19 | V1 プレート(Corning 7007)の実物: ウェル上端径、深さ、蓋なしの高さ、ホルダー内での A1 の位置 | 購入したロットで、ノギスとデプスゲージで測る | V1 の受け入れ条件(目標位置が底中心から 0.5 mm 以内)と安全高さの下限 | メーカー図面値
M23 | ヘッドの高さ(コレット先端 → ヘッドの最上点までの鉛直距離。8° ブロックに付け、チューブをクリップした状態) | 実物の V1 ホルダーで測る | コンデンサとの余裕と安全高さの上限。1 mm 高いと余裕が 1 mm 減る(上限 約 22.6 mm) | 22.2 mm(仮)

あわせて測ると後工程が楽になる項目があります。M9 照明支柱の位置と断面、M11 コンデンサを最上位置にしたときの空き、M12 接眼部の外形、M13 ステージハンドルと焦点ノブの位置、M16 定盤の穴ピッチ(M6/25 mm か ¼-20/1")、M17 手元のポンプの型式と外形、そして外部停止(インヒビット)入力の有無です。一覧は docs/05_measurement_checklist.md にあります。

M18 照明試験も組立前に済ませます。Ø10 mm 程度の棒をピントの 30–45 mm 上に、光軸から 0、4、8 mm ずらして置き、4× と 10× で像を撮ります。ホルダーが透過光をどれだけ遮るかを確かめ、8° のままでよいか、10–12° に傾けるべきかを決めます。

## 用意するもの

現段階では部品の種類と大きさの目安だけを示します。未確定 型番は実測のあとに決めます。

区分 | 内容(目安) | 備考
架台 | ベース板(Al 15 mm 厚)、支柱 80 × 80 × 2 本、Y 梁 80 × 80(長さ約 410 mm)、斜めブレース 2 本 | ベース板は長穴にして、X/Y ±15 mm、ヨー ±2° を調整できるようにする
直動ステージ | Y: ストローク 30 mm 以上、X: 100 mm 以上、Z: 50 mm(リード 1 mm のボールねじ) | X/Z は幅 20–26 mm 級の工業用ステージ(THK KR、MISUMI LX 級)を想定
モーター | NEMA17 × 3、原点スイッチ(NC)× 3、Z 基準スイッチ × 1 | Z はコンデンサの下で止まる「基準スイッチ」で原点を取る。上端スイッチは行き過ぎ防止用
ヘッド | キネマティックマウント(3 球 + 磁石)、ドッグレッグアーム(細い部分 12 × 12 mm、全長 120 mm)、コレットホルダー(Ø10、深さストップ付き) | 衝突するとアームが外れる構造にする
キャピラリ | OD 1.0/1.5/2.0 mm の 3 クラス。1 mm 級の対象には薄肉 2.00/1.56 mm を使う | 詳しくは docs/08_capillary_sizing.md
流体 | PTFE/FEP 1/16" チューブ(約 1.2 m)、固定クランプ、既存のシリンジポンプ | ポンプは架台に載せない
電気 | 24 V 電源、モーションコントローラ、TMC5160 級ドライバ × 3、非常停止(モーター電源を遮断) | docs/06_electrical.md
顕微鏡側 | IX-ULWCD コンデンサ、電動 XY ステージ(移動量 99 × 63 mm 以上。IX3-SSU は不足) | 手元の機材を先に確認する

## 部品候補リスト

図の番号から部品を引く「部品の対応表」は docs/13_part_map_ja.md(HTML 版 docs/assembly_ja/part_map_ja.html)にあります。番号付きの全体図とヘッド拡大図、実物・CAD・部品候補・組立工程・実測の対応をまとめています。

各品目の候補をまとめた一覧です(42 品目、P01–P42)。候補は検索結果の抜粋から集めたもので、型番、価格、納期は見積で確認します。凍結ゲートを通過するまで発注は確定しません。発注の順序と事前にやることは、別冊の「組立前にやること」(docs/11_pre_assembly_actions_ja.md)にあります。

先に確かめること。(1) IX-ULWCD コンデンサ(P09)は、地域によって入手できないという記載がありました。この設計は IX-ULWCD が前提なので、最初に Evident に在庫と納期を確認します。(2) 電動 XY ステージ(P07)は見積制で、納期も長くなりがちです。機種が決まると、架台が避けるべき外形も決まります。(3) X/Y/Z すべてに工業用ステージを使うと、ピッカー本体は約 25–35 万円になる見込みです(調査担当の推定)。20 万円前後に収めるなら、Y を安価な一体型ステージにします。(4) 1.0/1.5/2.0 mm の 3 サイズを確実に掴めて横ポートを持つ市販ホルダーは見つかりませんでした。ER8 コレットを使った自作ホルダーを第一候補にしています(P10)。ナット外径が Ø10 mm の想定より大きくなる可能性があります。

ID | 区分 | 品目 | 数量 | 第一候補 | 価格目安(抜粋) | 確認状況
P01 | Actuator | Z stage (vertical, landing axis) | 1 | THK KR20 LM Guide Actuator, lead 1: KR2001A-0080-P0-01A0 (precision) or KR2001A-0080-H0-01A0 (high-accuracy); 80 mm stroke, no cover | KR20: not found (used unit on eBay ~USD 108 + shipping); DRS2 with driver: not found | PNs verified (Oriental Motor THK listing); KR20 numeric repeatability per grade UNVERIFIED (THK accuracy table exists but values not seen)
P02 | Actuator | X stage (cantilevered, tip X) | 1 | MISUMI LX26 lead 2, precision grade: LX2602P-...-150 (or -100); example real PN LX2602-B1-A2625-100 (high grade, 100 mm); motor bracket code to configure for NEMA17 | LX26 base price JPY 43,000-66,600 (range across variants) | LX26 repeatability & strokes: excerpt, one source (MISUMI PDF); KR26 PNs verified via Oriental listing; price unverified
P03 | Actuator | Y stage (on fixed Y beam) | 1 | MISUMI LX26 (LX2602/LX2602P), shortest stroke >=50 mm; configure on site | LX26 JPY 43,000-66,600 (see P02) | partial (families verified; min strokes unverified)
P04 | Motor | NEMA17 stepper motors, X and Y | 2 | Oriental Motor PKP244D15A2 / PKP244D15B2 (PKP series, 42 mm, bipolar) | not found | PNs verified; torque of the -D15A2 variant unverified
P05 | Motor | NEMA17 stepper motor for Z (optional brake) | 1 | Oriental Motor PKP244D15A2 (no brake; baseline) | not found | PN seen (legacy); current brake PN unverified
P06 | Mechanical | Motor brackets + shaft couplings | 3 | THK KR20 / KR26 Direct Motor Mount (THK Store) or KR motor wrap | not found | partial
P07 | Microscope | Motorised XY stage for IX73 (W-B) | 1 | Märzhäuser SCANplus IM 120 x 80 for Olympus IX53/IX73/IX83, order no. 00-24-579-0000 (2 mm ball screw, integrated measuring system) | not found (quote required) | Märzhäuser order no. and Prior H117 114x75 travel: excerpt, 2 sources each; ASI travel UNVERIFIED
P08 | Microscope | Stage controller + joystick | 1 | Märzhäuser TANGO controller (for SCAN IM) | not found | partial
P09 | Microscope | IX-ULWCD long-working-distance condenser (if not owned) | 1 | Evident/Olympus IX-ULWCD (Olympus part 6-U220) new via Evident Japan | USD 974 list (NY state contract price file; older) ; USD 864 (2010 VA price list) | spec: reseller excerpts (2 agree); current Evident availability UNVERIFIED
P10 | Capillary holder | Collet capillary holder (custom) with inserts OD 1.0/1.5/2.0 | 1 body + 3 insert sets | Custom turned holder (SUS303/PEEK) using Rego-Fix ER8 collets Ø1.0 / Ø1.5 / Ø2.0 (0.5 mm clamping range each) + ER8 mini nut | ER8 collet ~USD 45 each (Rego-Fix, retailer); Eppendorf: not found | ER8 sizes verified (multiple vendors); ER8 nut OD vs Ø10 envelope UNVERIFIED (ER8 nuts are typically ~12-16 mm OD)
P11 | Capillary holder | Commercial pipette holder with side port (reference/spare, 1.0-2.0 mm) | 1-3 | WPI MPH series (MPH3, MPH4, MPH6S) - supplied for 1.0/1.2/1.5/2.0 mm OD glass; pressure-injection type, no half-cell | not found | PNs seen in excerpts; port thread / tubing interface UNVERIFIED
P12 | Mechanical | Kinematic magnetic break-away mount (Z carriage <-> arm) | 1 (+1 spare top plate) | Thorlabs KB25/M (25 x 25 mm, magnetic, ball/V-groove); top KBT25/M, bottom KBB25/M | KB25/M USD 75.60; KBT25/M or KBB25/M USD 39.90 each | verified (Thorlabs + reseller excerpts)
P13 | Mechanical | Exchangeable angle blocks 8 / 20 / 30 deg | 3 | Custom CNC (MISUMI meviy CNC milling, upload 3D CAD for instant quote) | not found (meviy instant quote) | n/a (custom)
P14 | Mechanical | Dog-leg arm (115 mm, 12x12 thin section) | 1 (+1 spare) | Custom CNC via MISUMI meviy (A7075 or SUS304) | not found | n/a (custom)
P15 | Mechanical | Carriage brackets (X carriage->Z body, Y carriage->X beam), tubing clamps | set | Custom CNC via MISUMI meviy | not found | n/a (custom)
P16 | Frame | Base plate, 15 mm aluminium, slotted for table grid | 1 | MISUMI meviy CNC milling (plate with slots, A5052) | not found (instant quote on meviy) | n/a (custom)
P17 | Frame | Posts, aluminium extrusion 80x80 | 2 | MISUMI HFS8-8080 (cut to length, 50-4000 mm) | USD 43.60/m (>=300 mm); USD 13.00 each (<300 mm) | price/spec: excerpt, one source
P18 | Frame | Y beam, aluminium extrusion 80x80, ~390 mm | 1 | MISUMI HFS8-8080 (L~390) | ~USD 17 (0.39 m x USD 43.60/m) | derived
P19 | Frame | X support beam, aluminium extrusion 40x80 (cantilever) | 1 | MISUMI HFS8-4080 | not found | partial (PN family seen, price not)
P20 | Frame | Extrusion fasteners: brackets, post-assembly nuts, diagonal braces, jack screw | set | MISUMI HFS8 brackets and post-insertion nuts (series; configure) | not found | n/a
P21 | Consumable | Glass capillaries class S: OD 1.0 / ID 0.58 | 1 pack | WPI 1B100-4 (1.0/0.58, 4 in) | not found | WPI: manifest S14; Narishige: excerpt
P22 | Consumable | Glass capillaries class M: OD 1.5 / ID 0.84-0.86 | 1 pack | WPI 1B150-4 (1.5/0.84) | not found | WPI/Sutter: manifest S14
P23 | Consumable | Glass capillaries class L: OD 2.0 / ID 1.12 | 1 pack | WPI 1B200-4 (2.0/1.12) | not found | manifest S14
P24 | Consumable | Glass capillaries class L': thin wall OD 2.00 / ID 1.56 | 1 pack | Sutter B200-156-10 (2.00/1.56, 10 cm, thin wall, no filament) | not found | Sutter PN: excerpt; WPI PN UNVERIFIED
P25 | Fluidics | PTFE/FEP tubing 1/16" OD | 1 roll (~3 m used) | IDEX Health & Science FEP tubing 1/16" OD x 0.030" ID, natural, 50 ft: 1520L | not found | 1520L verified (IDEX store)
P26 | Fluidics | Fittings 1/4-28 flat-bottom for 1/16" tubing (+ferrules, unions) | 1 kit | IDEX XP-235X flangeless fitting, short, PEEK, 1/4-28 FB, 1/16" (10/pk) | XP-235X USD 62.23 (IDEX US store; per 10-pack as listed) | XP-235X verified; ferrule PN unverified
P27 | Fluidics | Pump interface: Luer to 1/4-28 adapter (Harvard) / direct 1/4-28 (Tecan Cavro) | 1-2 | IDEX Luer adapters, female Luer to 1/4-28 (series; exact PN to configure on IDEX site) | not found | series only
P28 | Electronics | Motion controller (G-code / serial, >=3 axes, >=6 NC inputs) | 1 | Duet3D Duet 3 Mainboard 6HC (6 on-board TMC5160 drivers, 6.3 A peak, 9 IO ports, RepRapFirmware, USB/Ethernet) | Duet 6HC ~USD 231 (retailer, sold out) ; AliExpress listing USD 154 (clone risk) | Duet driver type verified (Duet docs + forum); Trinamic specs: excerpts
P29 | Electronics | TMC5160 stepper drivers (only if controller has sockets) | 3 (+1 spare) | BIGTREETECH TMC5160T Pro V1.0 (up to 56 V, SPI) | TMC5160T Pro: USD 133.19 per 4-pack (Amazon) | excerpt, one source each
P30 | Electronics | Home switches, NC / fail-safe (X out, Y front, Z top) + optional far limits | 3 (+3 optional) | Omron EE-SX672 / EE-SX674 slot photomicrosensor (5-24 V, NPN, Light-ON/Dark-ON selectable, 5 mm slot) | D2VW-5-1HS USD 3.6-5.5 ; optical: not found | verified (multiple distributors)
P31 | Electronics | 24 V DC PSU (~150 W) | 1 | Mean Well LRS-150-24 (24 V 6.5 A, 156 W, enclosed, 30 mm low profile) | not found (JPY); widely stocked | verified (several distributors)
P32 | Safety | E-stop push button (2NC) | 1 | IDEC XW1E-BV402M-R (40 mm push-lock/pull, 2NC, 22 mm hole) | not found | verified
P33 | Safety | Safety relay / contactor cutting motor 24 V (logic stays on) | 1 | Omron G9SE-201 (24 VDC, 2 safety NO + 1 aux, Cat.4/PLe, 17.5 mm DIN) | IDEC HR6S-AF1C USD 357 ; G9SE: not found | G9SE verified; DC switching rating at driver inrush UNVERIFIED
P34 | Wiring | Cable chains (X on Y group; Y on frame) | 2 | igus E2i.15 / B15i series (openable inner radius; configure width/radius) | not found (igus prices on request / configurator) | series verified; exact PN to configure
P35 | Wiring | Motor (shielded) and switch (twisted pair) cables, chain-rated | ~6 m each | igus chainflex shielded motor/control cable (series; exact CF type unverified) | not found | UNVERIFIED
P36 | Electronics | Enclosure, DIN rail, fuses, terminal blocks, USB cable | 1 set | Takachi / IDEC control box (series) | not found | n/a
P37 | Frame | Table mounting hardware | 1 set | MISUMI cap screws/washers (series) | not found | n/a
P38 | Fluidics | Syringe pump (existing Harvard or Tecan) - no purchase | 0 | Harvard Apparatus (model TBD, M17) | - | n/a
P39 | Microscope | SBS plate insert / holder for the motorised XY stage | 1 | Stage vendor's multiwell-plate insert for the chosen stage (Märzhäuser / Evident / Prior) — configure with the stage quote | not found | n/a (depends on P07)
P40 | Fluidics | Syringe for the existing pump (gas-tight) | 2 | Hamilton 1700-series gas-tight syringe, 25-100 uL (series; confirm pump clamp size) | not found | unverified (series only)
P41 | Fluidics | Optional pinch/NC valve and pressure tee on the fixed side | 1 | Normally-closed solenoid pinch valve for 1/16 in tubing (series; e.g. from fluidics vendors) | not found | unverified
P42 | Electronics | Z reference switch (below the condenser) | 1 | Omron EE-SX672 slot photomicrosensor (same as P30) | see P30 | see P30

英語版の全項目・出典: docs/12_parts_candidates.md。元データ: docs/parts/candidates.csv(この CSV を直すと手順書にも反映されます)。

## プレートと角度ブロック

キャピラリの角度は、交換式の角度ブロック(8° / 20° / 30°)で変えます。ブロックはアーム先端のホルダー座に入れ、ピン 2 本とねじ 1 本で固定します。傾くのはホルダーとキャピラリだけです。ウェルに入れるキャピラリの長さ(露出長)は、コレットの深さストップで合わせます。

プレート形式ごとの角度ブロックと露出長の断面図

先端をウェル底の中央に置いたときの断面。紫線はコンデンサ下端、点線は安全高さ(ウェル縁 + 5 mm)。

プレート | キャピラリ | 角度ブロック | 露出長 | ウェル縁との余裕 | コンデンサとの余裕(安全高さ) | 底面の到達範囲 | 透過光の遮り | 備考
96 U-bottom | S (OD 1.0) | 8° | 30 mm | 1.38 mm | 4.8 mm | 中央(U 底) | 33%
96 U-bottom | M (OD 1.5) | 8° | 30 mm | 1.13 mm | 4.8 mm | 中央(U 底) | 33%
96 U-bottom | L (OD 2.0) | 8° | 30 mm | 0.87 mm | 4.8 mm | 中央(U 底) | 33%
48-well | S (OD 1.0) | 8° | 24 mm | 2.87 mm | 4.7 mm | 54% | 43%
48-well | M (OD 1.5) | 8° | 24 mm | 2.62 mm | 4.7 mm | 48% | 43% | 底面の到達範囲が基準未満。0° ブロックなら広がるが透過光を大きく遮る(D8)
48-well | L (OD 2.0) | 8° | 24 mm | 2.37 mm | 4.7 mm | 42% | 43% | 底面の到達範囲が基準未満。0° ブロックなら広がるが透過光を大きく遮る(D8)
24-well | S (OD 1.0) | 8° | 24 mm | 5.22 mm | 4.7 mm | 67% | 43%
24-well | M (OD 1.5) | 8° | 24 mm | 4.97 mm | 4.7 mm | 62% | 43%
24-well | L (OD 2.0) | 8° | 24 mm | 4.72 mm | 4.7 mm | 57% | 43%
12-well | S (OD 1.0) | 20° | 27 mm | 4.57 mm | 3.7 mm | 56% | 14%
12-well | M (OD 1.5) | 20° | 27 mm | 4.33 mm | 3.7 mm | 52% | 14%
12-well | L (OD 2.0) | 8° | 24 mm | 7.94 mm | 4.6 mm | 69% | 43%
6-well | S (OD 1.0) | 30° | 30 mm | 6.98 mm | 4.2 mm | 57% | 0%
6-well | M (OD 1.5) | 30° | 30 mm | 6.76 mm | 4.2 mm | 55% | 0%
6-well | L (OD 2.0) | 30° | 30 mm | 6.55 mm | 4.2 mm | 53% | 0%

大きいウェルほど角度を急にでき、ホルダーが光路から外れて像が明るくなります。一方、6〜48-well は深さが約 17.4 mm あり、96-well より 6 mm 深いぶん、安全高さまで上げたときにヘッドがコンデンサへ近づきます。露出長と角度はこの二つの兼ね合いで決めています。45° は、どのプレートでも縁かプレート上面に近すぎるため用意しません。

ブロックを交換する手順。Z を基準スイッチまで上げ、X を待避位置(+85 mm)に動かしてから Z を上端にし、キャピラリを外してからブロックを差し替えます。露出長を合わせてキャピラリを付け直し、3 点校正をやり直します。コンデンサとの余裕は仮の外形で計算した値なので、M6 と M8 を測ったあとに見直します。要実測

## 組立工程 1–10

1

### ベース板を定盤に置き、位置を出す

工程1 ベース板

オレンジ: ベース板

1. IX73 の右側に、Y 梁の中心線が光軸から X = +368 mm になる位置でベース板を置きます。
2. Y 方向は、支柱が Y = -115 mm と +215 mm に来るようにします(Y は奥が +)。
3. 長穴の中央でボルトを仮締めします。本締めは工程 11 の校正のあとです。
- 要実測 M15 右側の空き、M16 定盤の穴ピッチ
- 本体側面との隙間は約 206 mm です。ステージハンドル(M13)に手が届くことを確認します。

2

### 支柱と斜めブレースを立てる

工程2 支柱

オレンジ: 支柱 2 本と斜めブレース

1. 支柱 2 本をベース板にボルト留めし、スコヤで直角を確認します。
2. 外側(+X 側)に斜めブレースを入れ、X 方向の倒れを抑えます。
- 支柱の長さは M1 で決まります。いまは定盤面から梁下面まで約 270 mm です(M1 = 200 mm を仮定)。要実測

3

### Y 梁を載せ、高さを合わせる

工程3 Y梁

オレンジ: Y 梁

1. Y 梁を支柱に載せ、縦長穴とジャッキボルトで高さを合わせます(調整幅 ±20 mm)。
2. 梁の上面が定盤と平行になるよう、水準器で確認します。
3. 高さの目安は、梁の下面がステージ上面から +70 mm です。
- 顕微鏡には触れません。梁と本体の間に手が入ることを確認します。

4

### Y ステージを取り付ける

工程4 Yステージ

オレンジ: Y ステージ本体、モーター、原点スイッチ

1. Y ステージを梁の上面に置き、梁の縁に当てて平行を出してから固定します。
2. モーターは奥側(+Y)、原点スイッチは手前側に付けます。
- ストロークは 30 mm 以上です。未確定 型番

5

### X 支持梁と X ステージを取り付ける

工程5 Xステージ

オレンジ: Y キャリッジ、X 支持梁、X ステージ、モーター、原点スイッチ

1. Y キャリッジの上に X 支持梁(40 × 80 以上の箱断面)を固定します。支持梁は光軸側へ片持ちで伸びます。
2. X ステージを支持梁の下面に吊り、テーブル面を手前(−Y)に向けます。
3. X ステージの光軸側の端は X = +60 mm で、コンデンサ半径より 20 mm 外側にあります。
- 要実測 M7 コンデンサ保持アームとの隙間は、仮の形状で数 mm しかありません。取り付け前に実物で確認します。

6

### Z ステージを取り付ける

工程6 Zステージ

オレンジ: X キャリッジブラケット、Z ステージ、Z モーター、上端リミットスイッチ、Z 基準スイッチ、Z キャリッジ

1. X キャリッジにブラケットを付け、Z ステージを鉛直に固定します。スコヤと水準器で鉛直を確認します。
2. Z には二つのスイッチを付けます。基準スイッチは、ヘッドの最上部がコンデンサ下端より 2 mm 低くなる高さに付けます(M8 を測ってから位置を決める)。上端スイッチは行き過ぎ防止用です。光軸の近くで Z を上端まで上げると、アームがコンデンサに当たります。
3. 電源を切った状態で Z キャリッジを手で押し、下がらないことを確かめます(リード 1 mm とモーターのディテントトルクで保持)。
- Z 本体はコンデンサの外側にあり、光軸から常に約 105 mm 以上離れています(先端が X -15 mm のとき)。

7

### ヘッドを取り付ける(キャピラリはまだ付けない)

工程7 ヘッド

オレンジ: キネマティックマウント、ドッグレッグアーム、コレットホルダー

1. Z キャリッジにキネマティックマウント(3 球 + 磁石)を付け、アームを載せます。
2. アームの薄い部分(12 × 12 mm、長さ 60 mm)がコンデンサの下に入り、先端のホルダーが光軸の真上に来ます。
3. 使うプレートに合う角度ブロック(8° / 20° / 30°)を入れて固定します。96-well なら 8° です(「プレートと角度ブロック」の表を参照)。
4. Z を安全高さ(19.4 mm)に置き、アームとコンデンサの隙間を目視で確認します。Z を上端まで上げるのは、X を待避位置(+85 mm)へ動かしてからにします。光軸の近くで Z を上端にすると、アームがコンデンサに当たります。
- 要実測 M8 ピント状態でのコンデンサ下端の高さ。余裕が 2 mm を切るなら、露出長を短くする、アームを薄くする、照明支柱を倒す案に切り替える、のいずれかで対応します。

8

### ケーブルを配線する

工程8 配線

オレンジ: X/Y ケーブルチェーン、コントローラ

1. モーターとスイッチのケーブルは、可動部の奥側(+Y)に通します。
2. X は Y 群に、Y は架台に、それぞれ小さなケーブルチェーンで逃がします。
3. 非常停止はモーター電源を切ります。ロジック電源は残し、停止した状態をコントローラが記録できるようにします。
4. 非常停止ではポンプと電動ステージも止めます。ポンプは、外部停止入力があればそれを安全リレーの空き接点につなぎます。なければ専用のデジタル入力、それもなければコントローラからの停止コマンドに加えて、電源が切れると閉じる常閉ピンチバルブを入れます。
5. 非常停止を解除しても自動では再開しません。PC で確認したあと、Z を基準へ、X を待避位置へ、Y の順に原点復帰し、チューブとキャピラリを点検してから最後にポンプを戻します。
- ケーブルがヘッドを引っ張らないよう、全ストロークを手で動かして確認します。

9

### チューブを通して液を満たす

工程9 チューブ

オレンジ: チューブ、各クランプ、既存のシリンジポンプ

1. チューブはホルダー上部から出し、アームの側面の溝に沿わせます。アームの上面はコンデンサに最も近いので通しません。
2. Z キャリッジ → Z 本体 → 架台の固定クランプ → ポンプの順に留め、Z と X/Y のそれぞれにサービスループ(曲げ半径 25 mm 以上)を作ります。
3. ポンプ側からゆっくり液を送り、気泡を追い出します。チューブは可動部の手前側(−Y)を通し、ケーブルと分けます。
- ポンプ、ピンチバルブ、圧力分岐は固定側に置きます。ヘッドには載せません。

10

### キャピラリを装着する

工程10 キャピラリ

オレンジ: ガラスキャピラリ(OD 1.0 / ID 0.6 / L 40 の場合)

1. Z を基準スイッチまで上げ、X を +85 mm の待避位置へ動かしてから、Z を上端にします。コンデンサの外で作業します。
2. 対象サイズに合うコレットインサートを入れます。深さストップをプレートに合う露出長(96-well は 30 mm。他は「プレートと角度ブロック」の表を参照)に合わせ、キャピラリを突き当てるまで差し込みます。
3. コレットを締め、端面の O リングで液が漏れないか確認します。
- キャピラリを交換したら、必ず工程 11 の 3 点校正をやり直します(先端位置は最大 ±0.5 mm ずれます)。

## 立ち上げと校正

組み立て後は、乾いた状態で動作を確かめてから液を使います。

1. 原点復帰。Z をゆっくり上げて基準スイッチで止め、次に X を待避位置(+85 mm)へ動かし、最後に Y の原点を取ります。基準スイッチは物理的に 1 個だけで、角度ブロックを替えても同じ位置です。その高さではアームがコンデンサに当たらず、先端はどのヘッドでも安全高さの通路(下記)の中にあります(V1 では先端 22.13 mm)。停電のあと先端がウェルに入ったままでも、この順序なら真上に抜けてから横へ動きます。
2. Z を上げてよい場所。Z を基準スイッチより上に上げるのは、X が待避位置にあるときだけにします。W-A のようにアームが長い場合、光軸から離れた位置でもアームがコンデンサの下に入るため、「光軸の周りの円筒」では判定できません。この規則を制御側に入れます。
3. ステージは安全高さの通路の中でだけ動かす。通路の下限は、動くプレートやクリップの最上部 + 5 mm、上限は、ヘッドの最上点がコンデンサの下端から 2 mm 以上離れる高さです。V1 では先端 19.35–22.18 mm(幅 2.83 mm)です。先端を吸引高さのまま電動ステージを動かすと、キャピラリがプレートを引きずります。制御側で禁止します。
4. 3 点校正。光軸付近の 3 点で先端を画像中心に合わせ、画像座標とピッカー座標を対応づけます(SpheroidPicker と同じ方法)。
5. 着地試験。空のウェルで、記録した底の少し上(約 50 µm)から 10 µm/s で降ろし、底からの離れ(目安 0.1–0.3 mm)を決めます。
6. M18 照明試験の確認。組み立てた実機で、ホルダーが像をどれだけ暗くするかを 4×/10× で確認します。
7. ここで本締め。ベース板と梁のボルトを本締めし、3 点校正をもう一度行います。

## 安全の決まりごと

- Z の原点は基準スイッチ(コンデンサの下)で取ります。上端は安全な位置ではありません。停電や非常停止でも Z が落ちないことを、工程 6 で確認しておきます。
- ヘッドはキネマティックマウントで付いているので、強くぶつかると外れます。これは位置を再現よく戻すための機構で、力を制限する安全装置ではありません。外れる力は先端で約 1.7 N で、どのキャピラリの折れる力(0.15–1.18 N の見積り)よりも大きいので、ガラスキャピラリは先に折れます。プレートは守れます。キャピラリは消耗品として扱い、外れたら付け直して 3 点校正をやり直します。
- キャピラリの交換は待避位置(X +85 mm)で、Z を上端にしてから行います。
- V1 で使うプレートは Corning 7007(96 穴 U 底)だけです。ほかのプレート(48-well (Corning 3548), 24-well (Corning 3524), 12-well (Corning 3513), 6-well (Corning 3516))は試験扱いで、V1 の受け入れ条件には入りません。
- プレートの蓋は作業前に外します。蓋があると高さが約 2 mm 増えます(Corning 7007 は蓋込み 16.5 mm)。

## まだ決まっていないこと

- 未確定 電動 XY ステージの機種(移動量 99 × 63 mm 以上。IX3-SSU は 76 × 52 mm で不足。Märzhäuser SCAN IM の 120 × 80 mm 級が候補)
- 未確定 各直動ステージとモーターの型番、ブラケット形状
- 未確定 アームの長さと厚み(M6–M8 次第)、キャピラリの最終角度(M18 次第)
- 未確定 支柱の長さ(M1 次第)、ベース板の穴配置(M16 次第)
- 寸法を変えるときは cad/params.py だけを書き換え、python tools/build_all.py を実行すると、この手順書の数値も含めて更新されます。

### まだ仮の値(自動で集計した一覧、19 件)

パラメータ | いまの値 | 内容 / 対応する実測項目
MULTIWELL_HEIGHT_EXTRA | 3.0 | multiwell plate top above the well rim/bottom-depth (plate height unknown, M19)
IX73_DECKS | 1 | number of decks on the lab's IX73 (M5)
STAGE_TOP_ABOVE_TABLE | 200.0 | NOT FOUND in any reachable source -> measure M1
STAGE_T | 20.0 | stage plate thickness (M3)
BODY_Y_FRONT | -235.0 | front face of body rel. optical axis (M5)
STAGE_CENTER_Y | 0.0 | stage assumed centred on optical axis (M4)
PILLAR_W | 90.0 | IX3-ILL pillar width (M9)
PILLAR_Y0 | 150.0 | front face of pillar rel. optical axis (M9)
PILLAR_Y1 | 240.0 | rear face of pillar
COND_ARM_W | 90.0 | condenser holder / arm width (M7)
COND_D | 80.0 | condenser outer diameter (M6)
COND_BODY_H | 70.0 | condenser body height (M6)
COND_PROFILE | [(80.0, 70.0)] | condenser (diameter, height) steps from the front (M6, M8)
MOTOR_STAGE_ENVELOPE | | record plan size, frame height above insert, cable exit and controller (M3, O-2)
OBS_TUBE_BOX | | observation tube + eyepieces envelope (M12)
STAGE_HANDLE | | IX3-SVR right-hand coaxial handle (M13)
OBJECTIVE_ZONE | | nosepiece/objectives under stage (M14)
STAGE_CLIP_TOP | 14.35 | highest moving stage/insert/clip feature above the datum, other than the plate (M3)
PLATE_FORCE_LIMIT | 5.0 | acceptable force on the plate bottom before damage [N] (to be defined)

出典と各数値の確度は docs/source_manifest.md にあります。IX73 の本体寸法(W 323 × D 475 × H 656 mm)とコンデンサの作動距離はメーカー値ですが、配置と形状の多くは仮の値です。

## この手順書の更新

この手順書は cad/params.py から自動で作られます。実測値や部品が決まったら、params.py の該当する値を書き換え、状態を PH から MEAS や MFR に変えてください。そのうえで python tools/build_all.py を実行すると、CAD、干渉チェック、図、英語の文書、この手順書の数値と図がまとめて更新されます。仮の値の一覧も自動で短くなります。

文章そのものを直すときは、docs/assembly_ja/guide.src.html を編集します。生成された assembly_guide_ja.html は直接編集しないでください。

### 最近の変更

- 2026-09-26: Review follow-up: single V1 target radius, mount wording, stroke metadata
- 2026-09-26: Address issues #4-#10: V1 plate freeze, safe-Z corridor, head consistency, provenance, CI
- 2026-09-26: Merge pull request #3 from Iwamo-yu/claude/zen-hopper-eyc1eb
- 2026-09-26: Address full review: Z reference homing, head-top allowance, per-class angle blocks
- 2026-09-26: Add pre-assembly action list, parts candidates; fix doc inconsistencies
- 2026-09-26: Merge remote-tracking branch 'origin/main' into claude/zen-hopper-eyc1eb
- 2026-09-26: Plate formats (6-96 well) with exchangeable angle blocks; auto-updating guide
- 2026-09-26: Merge pull request #2 from Iwamo-yu/claude/zen-hopper-eyc1eb

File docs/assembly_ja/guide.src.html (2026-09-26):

picker_ / 第1段階(配置検討)更新: {{BUILD_INFO}}未実測の仮値: {{PH_COUNT}} 件前提ワークフロー: W-B(ステージが各ウェルを光軸へ運ぶ)数値は cad/params.py から自動生成

# IX73 キャピラリピッカー 組立手順書

IX73 の右側に独立した架台を置き、XYZ ピッカーを組み立てて調整するまでの流れを、図と文章で示します。現時点の部品は外形だけの概念モデルで、型番は決まっていません。赤い【要実測】の値を測って入力するまで、ブラケット設計や部品発注に進まないでください。

その工程で取り付ける部品(図中のオレンジ) 要実測 実機で測る値 未確定 部品・寸法がまだ決まっていない

## 全体像

ピッカーは顕微鏡に一切触れません。光学定盤にボルト留めした架台(ベース板、支柱 2 本、Y 梁)に、Y → X → Z の順で直動ステージを積みます。Z ステージの先端から薄い「ドッグレッグアーム」をコンデンサの下へ差し込み、垂直から 8° 傾けたガラスキャピラリを保持します。

ウェルを選ぶのは顕微鏡ステージの役目です。ステージが対象ウェルを光軸へ運び、ピッカーは光軸付近だけを動きます。そのためピッカーの移動量は X {{WB_TRAVEL_X}} × Y {{WB_TRAVEL_Y}} × Z {{WB_TRAVEL_Z}} mm で足ります。X のうち +側は、キャピラリ交換のための待避位置として使います。

IX73 と右側のピッカー架台の全体図

全体図(W-B)。灰色は IX73 の仮外形、紫はコンデンサ(IX-ULWCD)、濃い青は架台と直動ステージ、緑はヘッド、黄はチューブ。

流体経路と動作系の機能図

流体経路(既存のシリンジポンプ → チューブ → キャピラリ)と動作系(PC → コントローラ → XYZ)は機械的に独立しており、ホルダーだけで結合します。

## 組立前の実測

凍結条件。次の {{FREEZE_GATE_N}} 項目({{FREEZE_GATE}})を測り、cad/params.py に入れて再計算するまで、寸法を確定しません。現在のモデルでコンデンサ付近の余裕は約 {{SW_WB_R08_ULWCD_SAFE_CLEAR}} mm ですが、これは仮の外形から出た数字です。

実測箇所を赤で示した正面図と側面図

赤が実測箇所。灰色の IX73 は仮の外形で、実寸ではありません。

ID | 測るもの | 測り方 | 何が決まるか | 現在のモデル値
M1 | 定盤面 → ステージ上面(プレートを置く面) | ハイトゲージか直尺で、ステージ中央付近の 3 点を測る | 支柱と梁の高さ | {{STAGE_TOP}} mm(仮)
M3 | ステージ外形、プレートホルダー、クリップ類のプレート上面からの突出 | 上から撮影し、ノギスで突出高さを測る | アームとプレート周辺の余裕 | 232 × 240 mm(平ステージの仕様値)
M4 | ステージ中心と光軸のずれ、ステージ固定の可否 | 低倍で視野中心に印を合わせ、ステージ目盛りを記録する | ステージの移動範囲の使い方 | 中心一致を仮定
M6 | 実際に使うコンデンサの型式と外径 | 型式ラベルを確認し、ノギスで外径を測る | アームの薄い部分の長さ(現在 {{WB_THIN_L}} mm) | Ø{{COND_D}} mm(仮)
M7 | コンデンサ保持アームの幅と最下点 | 正面から幅を、定盤から最下点の高さを測る | X 支持梁との干渉 | 幅 {{COND_ARM_W:.0f}} mm(仮)
M8 | ピントを合わせた状態での、プレート上面 → コンデンサ下端の距離 | 4× と 10× で、実際の観察状態のまま測る | コンデンサ下の余裕(最も効く値) | WD 73 mm からの推定
M10 | 照明支柱を後ろへ倒したときの外形 | 倒した状態で側面から撮影し、後方への張り出しを測る | コンデンサなしで運用する場合の代替案 | 仮
M15 | IX73 本体の右側面から定盤端までの空き | 巻尺で奥行き方向にも測る。他の機器の位置も記録する | 架台を置けるか(必要: 光軸から +{{WB_FOOT_X}} mm 程度) | 十分と仮定
M19 | V1 プレート({{V1_PLATE_SKU}})の実物: ウェル上端径、深さ、蓋なしの高さ、ホルダー内での A1 の位置 | 購入したロットで、ノギスとデプスゲージで測る | V1 の受け入れ条件(目標位置が底中心から {{V1_TARGET_R:.1f}} mm 以内)と安全高さの下限 | メーカー図面値
M23 | ヘッドの高さ(コレット先端 → ヘッドの最上点までの鉛直距離。{{V1_THETA:.0f}}° ブロックに付け、チューブをクリップした状態) | 実物の V1 ホルダーで測る | コンデンサとの余裕と安全高さの上限。1 mm 高いと余裕が 1 mm 減る(上限 約 {{NOSE_TOP_MAX_MIN:.1f}} mm) | {{NOSE_TOP_V1:.1f}} mm(仮)

あわせて測ると後工程が楽になる項目があります。M9 照明支柱の位置と断面、M11 コンデンサを最上位置にしたときの空き、M12 接眼部の外形、M13 ステージハンドルと焦点ノブの位置、M16 定盤の穴ピッチ(M6/25 mm か ¼-20/1")、M17 手元のポンプの型式と外形、そして外部停止(インヒビット)入力の有無です。一覧は docs/05_measurement_checklist.md にあります。

M18 照明試験も組立前に済ませます。Ø10 mm 程度の棒をピントの 30–45 mm 上に、光軸から 0、4、8 mm ずらして置き、4× と 10× で像を撮ります。ホルダーが透過光をどれだけ遮るかを確かめ、8° のままでよいか、10–12° に傾けるべきかを決めます。

## 用意するもの

現段階では部品の種類と大きさの目安だけを示します。未確定 型番は実測のあとに決めます。

区分 | 内容(目安) | 備考
架台 | ベース板(Al 15 mm 厚)、支柱 80 × 80 × 2 本、Y 梁 80 × 80(長さ約 {{WB_Y_BEAM_LEN}} mm)、斜めブレース 2 本 | ベース板は長穴にして、X/Y ±15 mm、ヨー ±2° を調整できるようにする
直動ステージ | Y: ストローク {{WB_TRAVEL_Y}} mm 以上、X: {{WB_TRAVEL_X}} mm 以上、Z: {{WB_TRAVEL_Z}} mm(リード 1 mm のボールねじ) | X/Z は幅 20–26 mm 級の工業用ステージ(THK KR、MISUMI LX 級)を想定
モーター | NEMA17 × 3、原点スイッチ(NC)× 3、Z 基準スイッチ × 1 | Z はコンデンサの下で止まる「基準スイッチ」で原点を取る。上端スイッチは行き過ぎ防止用
ヘッド | キネマティックマウント(3 球 + 磁石)、ドッグレッグアーム(細い部分 {{ARM_T_TXT}}、全長 {{WB_ARM_L}} mm)、コレットホルダー(Ø10、深さストップ付き) | 衝突するとアームが外れる構造にする
キャピラリ | OD 1.0/1.5/2.0 mm の 3 クラス。1 mm 級の対象には薄肉 2.00/1.56 mm を使う | 詳しくは docs/08_capillary_sizing.md
流体 | PTFE/FEP 1/16" チューブ(約 1.2 m)、固定クランプ、既存のシリンジポンプ | ポンプは架台に載せない
電気 | 24 V 電源、モーションコントローラ、TMC5160 級ドライバ × 3、非常停止(モーター電源を遮断) | docs/06_electrical.md
顕微鏡側 | IX-ULWCD コンデンサ、電動 XY ステージ(移動量 99 × 63 mm 以上。IX3-SSU は不足) | 手元の機材を先に確認する

## 部品候補リスト

図の番号から部品を引く「部品の対応表」は docs/13_part_map_ja.md(HTML 版 docs/assembly_ja/part_map_ja.html)にあります。番号付きの全体図とヘッド拡大図、実物・CAD・部品候補・組立工程・実測の対応をまとめています。

各品目の候補をまとめた一覧です(42 品目、P01–P42)。候補は検索結果の抜粋から集めたもので、型番、価格、納期は見積で確認します。凍結ゲートを通過するまで発注は確定しません。発注の順序と事前にやることは、別冊の「組立前にやること」(docs/11_pre_assembly_actions_ja.md)にあります。

先に確かめること。(1) IX-ULWCD コンデンサ(P09)は、地域によって入手できないという記載がありました。この設計は IX-ULWCD が前提なので、最初に Evident に在庫と納期を確認します。(2) 電動 XY ステージ(P07)は見積制で、納期も長くなりがちです。機種が決まると、架台が避けるべき外形も決まります。(3) X/Y/Z すべてに工業用ステージを使うと、ピッカー本体は約 25–35 万円になる見込みです(調査担当の推定)。20 万円前後に収めるなら、Y を安価な一体型ステージにします。(4) 1.0/1.5/2.0 mm の 3 サイズを確実に掴めて横ポートを持つ市販ホルダーは見つかりませんでした。ER8 コレットを使った自作ホルダーを第一候補にしています(P10)。ナット外径が Ø10 mm の想定より大きくなる可能性があります。

{{PARTS_TABLE}}

英語版の全項目・出典: docs/12_parts_candidates.md。元データ: docs/parts/candidates.csv(この CSV を直すと手順書にも反映されます)。

## プレートと角度ブロック

キャピラリの角度は、交換式の角度ブロック({{ANGLE_BLOCKS_TXT}})で変えます。ブロックはアーム先端のホルダー座に入れ、ピン 2 本とねじ 1 本で固定します。傾くのはホルダーとキャピラリだけです。ウェルに入れるキャピラリの長さ(露出長)は、コレットの深さストップで合わせます。

プレート形式ごとの角度ブロックと露出長の断面図

先端をウェル底の中央に置いたときの断面。紫線はコンデンサ下端、点線は安全高さ(ウェル縁 + 5 mm)。

プレート | キャピラリ | 角度ブロック | 露出長 | ウェル縁との余裕 | コンデンサとの余裕(安全高さ) | 底面の到達範囲 | 透過光の遮り | 備考

{{FMT_TABLE_JA}}

大きいウェルほど角度を急にでき、ホルダーが光路から外れて像が明るくなります。一方、6〜48-well は深さが約 17.4 mm あり、96-well より 6 mm 深いぶん、安全高さまで上げたときにヘッドがコンデンサへ近づきます。露出長と角度はこの二つの兼ね合いで決めています。45° は、どのプレートでも縁かプレート上面に近すぎるため用意しません。

ブロックを交換する手順。Z を基準スイッチまで上げ、X を待避位置(+{{WB_X_MAX}} mm)に動かしてから Z を上端にし、キャピラリを外してからブロックを差し替えます。露出長を合わせてキャピラリを付け直し、3 点校正をやり直します。コンデンサとの余裕は仮の外形で計算した値なので、M6 と M8 を測ったあとに見直します。要実測

## 組立工程 1–10

1

### ベース板を定盤に置き、位置を出す

工程1 ベース板

オレンジ: ベース板

1. IX73 の右側に、Y 梁の中心線が光軸から X = +{{WB_TOWER_X}} mm になる位置でベース板を置きます。
2. Y 方向は、支柱が Y = {{WB_POST_Y0}} mm と +{{WB_POST_Y1}} mm に来るようにします(Y は奥が +)。
3. 長穴の中央でボルトを仮締めします。本締めは工程 11 の校正のあとです。
- 要実測 M15 右側の空き、M16 定盤の穴ピッチ
- 本体側面との隙間は約 {{WB_GAP:.0f}} mm です。ステージハンドル(M13)に手が届くことを確認します。

2

### 支柱と斜めブレースを立てる

工程2 支柱

オレンジ: 支柱 2 本と斜めブレース

1. 支柱 2 本をベース板にボルト留めし、スコヤで直角を確認します。
2. 外側(+X 側)に斜めブレースを入れ、X 方向の倒れを抑えます。
- 支柱の長さは M1 で決まります。いまは定盤面から梁下面まで約 {{BEAM_ABOVE_TABLE:.0f}} mm です(M1 = {{STAGE_TOP}} mm を仮定)。要実測

3

### Y 梁を載せ、高さを合わせる

工程3 Y梁

オレンジ: Y 梁

1. Y 梁を支柱に載せ、縦長穴とジャッキボルトで高さを合わせます(調整幅 ±20 mm)。
2. 梁の上面が定盤と平行になるよう、水準器で確認します。
3. 高さの目安は、梁の下面がステージ上面から +{{BEAM_Z0:.0f}} mm です。
- 顕微鏡には触れません。梁と本体の間に手が入ることを確認します。

4

### Y ステージを取り付ける

工程4 Yステージ

オレンジ: Y ステージ本体、モーター、原点スイッチ

1. Y ステージを梁の上面に置き、梁の縁に当てて平行を出してから固定します。
2. モーターは奥側(+Y)、原点スイッチは手前側に付けます。
- ストロークは {{WB_TRAVEL_Y}} mm 以上です。未確定 型番

5

### X 支持梁と X ステージを取り付ける

工程5 Xステージ

オレンジ: Y キャリッジ、X 支持梁、X ステージ、モーター、原点スイッチ

1. Y キャリッジの上に X 支持梁(40 × 80 以上の箱断面)を固定します。支持梁は光軸側へ片持ちで伸びます。
2. X ステージを支持梁の下面に吊り、テーブル面を手前(−Y)に向けます。
3. X ステージの光軸側の端は X = +{{WB_X_LO:.0f}} mm で、コンデンサ半径より {{WB_X_INNER_CLEAR:.0f}} mm 外側にあります。
- 要実測 M7 コンデンサ保持アームとの隙間は、仮の形状で数 mm しかありません。取り付け前に実物で確認します。

6

### Z ステージを取り付ける

工程6 Zステージ

オレンジ: X キャリッジブラケット、Z ステージ、Z モーター、上端リミットスイッチ、Z 基準スイッチ、Z キャリッジ

1. X キャリッジにブラケットを付け、Z ステージを鉛直に固定します。スコヤと水準器で鉛直を確認します。
2. Z には二つのスイッチを付けます。基準スイッチは、ヘッドの最上部がコンデンサ下端より {{Z_REF_MARGIN:.0f}} mm 低くなる高さに付けます(M8 を測ってから位置を決める)。上端スイッチは行き過ぎ防止用です。光軸の近くで Z を上端まで上げると、アームがコンデンサに当たります。
3. 電源を切った状態で Z キャリッジを手で押し、下がらないことを確かめます(リード 1 mm とモーターのディテントトルクで保持)。
- Z 本体はコンデンサの外側にあり、光軸から常に約 {{WB_Z_MIN_DIST:.0f}} mm 以上離れています(先端が X {{WB_X_MIN}} mm のとき)。

7

### ヘッドを取り付ける(キャピラリはまだ付けない)

工程7 ヘッド

オレンジ: キネマティックマウント、ドッグレッグアーム、コレットホルダー

1. Z キャリッジにキネマティックマウント(3 球 + 磁石)を付け、アームを載せます。
2. アームの薄い部分({{ARM_T_TXT}}、長さ {{WB_THIN_L}} mm)がコンデンサの下に入り、先端のホルダーが光軸の真上に来ます。
3. 使うプレートに合う角度ブロック({{ANGLE_BLOCKS_TXT}})を入れて固定します。96-well なら {{FMT96_S_ANGLE:.0f}}° です(「プレートと角度ブロック」の表を参照)。
4. Z を安全高さ({{SAFE_Z:.1f}} mm)に置き、アームとコンデンサの隙間を目視で確認します。Z を上端まで上げるのは、X を待避位置(+{{WB_X_MAX}} mm)へ動かしてからにします。光軸の近くで Z を上端にすると、アームがコンデンサに当たります。
- 要実測 M8 ピント状態でのコンデンサ下端の高さ。余裕が {{MIN_MARGIN:.0f}} mm を切るなら、露出長を短くする、アームを薄くする、照明支柱を倒す案に切り替える、のいずれかで対応します。

8

### ケーブルを配線する

工程8 配線

オレンジ: X/Y ケーブルチェーン、コントローラ

1. モーターとスイッチのケーブルは、可動部の奥側(+Y)に通します。
2. X は Y 群に、Y は架台に、それぞれ小さなケーブルチェーンで逃がします。
3. 非常停止はモーター電源を切ります。ロジック電源は残し、停止した状態をコントローラが記録できるようにします。
4. 非常停止ではポンプと電動ステージも止めます。ポンプは、外部停止入力があればそれを安全リレーの空き接点につなぎます。なければ専用のデジタル入力、それもなければコントローラからの停止コマンドに加えて、電源が切れると閉じる常閉ピンチバルブを入れます。
5. 非常停止を解除しても自動では再開しません。PC で確認したあと、Z を基準へ、X を待避位置へ、Y の順に原点復帰し、チューブとキャピラリを点検してから最後にポンプを戻します。
- ケーブルがヘッドを引っ張らないよう、全ストロークを手で動かして確認します。

9

### チューブを通して液を満たす

工程9 チューブ

オレンジ: チューブ、各クランプ、既存のシリンジポンプ

1. チューブはホルダー上部から出し、アームの側面の溝に沿わせます。アームの上面はコンデンサに最も近いので通しません。
2. Z キャリッジ → Z 本体 → 架台の固定クランプ → ポンプの順に留め、Z と X/Y のそれぞれにサービスループ(曲げ半径 25 mm 以上)を作ります。
3. ポンプ側からゆっくり液を送り、気泡を追い出します。チューブは可動部の手前側(−Y)を通し、ケーブルと分けます。
- ポンプ、ピンチバルブ、圧力分岐は固定側に置きます。ヘッドには載せません。

10

### キャピラリを装着する

工程10 キャピラリ

オレンジ: ガラスキャピラリ(OD 1.0 / ID 0.6 / L 40 の場合)

1. Z を基準スイッチまで上げ、X を +{{WB_X_MAX}} mm の待避位置へ動かしてから、Z を上端にします。コンデンサの外で作業します。
2. 対象サイズに合うコレットインサートを入れます。深さストップをプレートに合う露出長(96-well は {{FMT96_S_EXP:.0f}} mm。他は「プレートと角度ブロック」の表を参照)に合わせ、キャピラリを突き当てるまで差し込みます。
3. コレットを締め、端面の O リングで液が漏れないか確認します。
- キャピラリを交換したら、必ず工程 11 の 3 点校正をやり直します(先端位置は最大 ±0.5 mm ずれます)。

## 立ち上げと校正

組み立て後は、乾いた状態で動作を確かめてから液を使います。

1. 原点復帰。Z をゆっくり上げて基準スイッチで止め、次に X を待避位置(+{{WB_X_MAX}} mm)へ動かし、最後に Y の原点を取ります。基準スイッチは物理的に 1 個だけで、角度ブロックを替えても同じ位置です。その高さではアームがコンデンサに当たらず、先端はどのヘッドでも安全高さの通路(下記)の中にあります(V1 では先端 {{ZREF_TIP_R08:.2f}} mm)。停電のあと先端がウェルに入ったままでも、この順序なら真上に抜けてから横へ動きます。
2. Z を上げてよい場所。Z を基準スイッチより上に上げるのは、X が待避位置にあるときだけにします。W-A のようにアームが長い場合、光軸から離れた位置でもアームがコンデンサの下に入るため、「光軸の周りの円筒」では判定できません。この規則を制御側に入れます。
3. ステージは安全高さの通路の中でだけ動かす。通路の下限は、動くプレートやクリップの最上部 + {{CORRIDOR_LOWER_MARGIN:.0f}} mm、上限は、ヘッドの最上点がコンデンサの下端から {{MIN_MARGIN:.0f}} mm 以上離れる高さです。V1 では先端 {{CORR_R08_LO:.2f}}–{{CORR_R08_HI:.2f}} mm(幅 {{CORR_R08_W:.2f}} mm)です。先端を吸引高さのまま電動ステージを動かすと、キャピラリがプレートを引きずります。制御側で禁止します。
4. 3 点校正。光軸付近の 3 点で先端を画像中心に合わせ、画像座標とピッカー座標を対応づけます(SpheroidPicker と同じ方法)。
5. 着地試験。空のウェルで、記録した底の少し上(約 50 µm)から 10 µm/s で降ろし、底からの離れ(目安 0.1–0.3 mm)を決めます。
6. M18 照明試験の確認。組み立てた実機で、ホルダーが像をどれだけ暗くするかを 4×/10× で確認します。
7. ここで本締め。ベース板と梁のボルトを本締めし、3 点校正をもう一度行います。

## 安全の決まりごと

- Z の原点は基準スイッチ(コンデンサの下)で取ります。上端は安全な位置ではありません。停電や非常停止でも Z が落ちないことを、工程 6 で確認しておきます。
- ヘッドはキネマティックマウントで付いているので、強くぶつかると外れます。これは位置を再現よく戻すための機構で、力を制限する安全装置ではありません。外れる力は先端で約 {{BREAK_RELEASE_N:.1f}} N で、どのキャピラリの折れる力({{BREAK_MIN_N:.2f}}–{{BREAK_MAX_N:.2f}} N の見積り)よりも大きいので、ガラスキャピラリは先に折れます。プレートは守れます。キャピラリは消耗品として扱い、外れたら付け直して 3 点校正をやり直します。
- キャピラリの交換は待避位置(X +{{WB_X_MAX}} mm)で、Z を上端にしてから行います。
- V1 で使うプレートは {{V1_PLATE_SKU}}(96 穴 U 底)だけです。ほかのプレート({{EXPERIMENTAL_PLATES}})は試験扱いで、V1 の受け入れ条件には入りません。
- プレートの蓋は作業前に外します。蓋があると高さが約 2 mm 増えます(Corning 7007 は蓋込み 16.5 mm)。

## まだ決まっていないこと

- 未確定 電動 XY ステージの機種(移動量 99 × 63 mm 以上。IX3-SSU は 76 × 52 mm で不足。Märzhäuser SCAN IM の 120 × 80 mm 級が候補)
- 未確定 各直動ステージとモーターの型番、ブラケット形状
- 未確定 アームの長さと厚み(M6–M8 次第)、キャピラリの最終角度(M18 次第)
- 未確定 支柱の長さ(M1 次第)、ベース板の穴配置(M16 次第)
- 寸法を変えるときは cad/params.py だけを書き換え、python tools/build_all.py を実行すると、この手順書の数値も含めて更新されます。

### まだ仮の値(自動で集計した一覧、{{PH_COUNT}} 件)

パラメータ | いまの値 | 内容 / 対応する実測項目

{{PH_TABLE}}

出典と各数値の確度は docs/source_manifest.md にあります。IX73 の本体寸法(W 323 × D 475 × H 656 mm)とコンデンサの作動距離はメーカー値ですが、配置と形状の多くは仮の値です。

## この手順書の更新

この手順書は cad/params.py から自動で作られます。実測値や部品が決まったら、params.py の該当する値を書き換え、状態を PH から MEAS や MFR に変えてください。そのうえで python tools/build_all.py を実行すると、CAD、干渉チェック、図、英語の文書、この手順書の数値と図がまとめて更新されます。仮の値の一覧も自動で短くなります。

文章そのものを直すときは、docs/assembly_ja/guide.src.html を編集します。生成された assembly_guide_ja.html は直接編集しないでください。

### 最近の変更

{{CHANGELOG}}

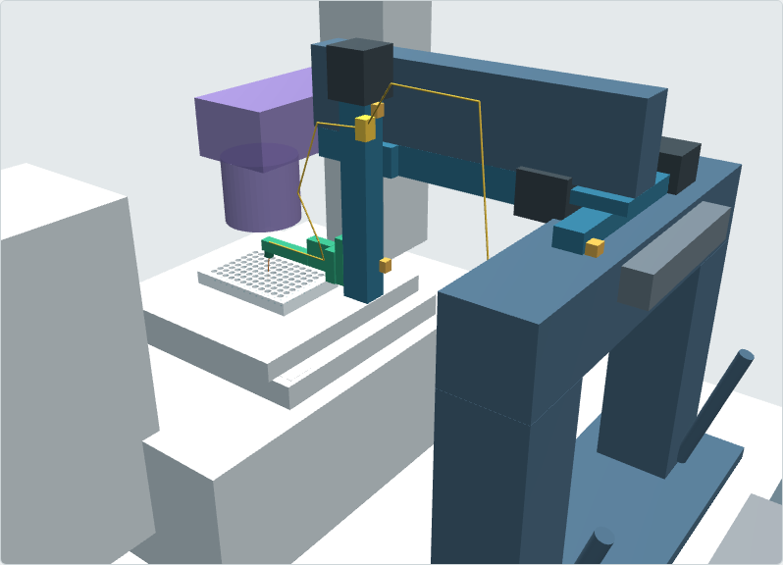
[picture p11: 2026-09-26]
docs/assembly_ja/img/step10.png

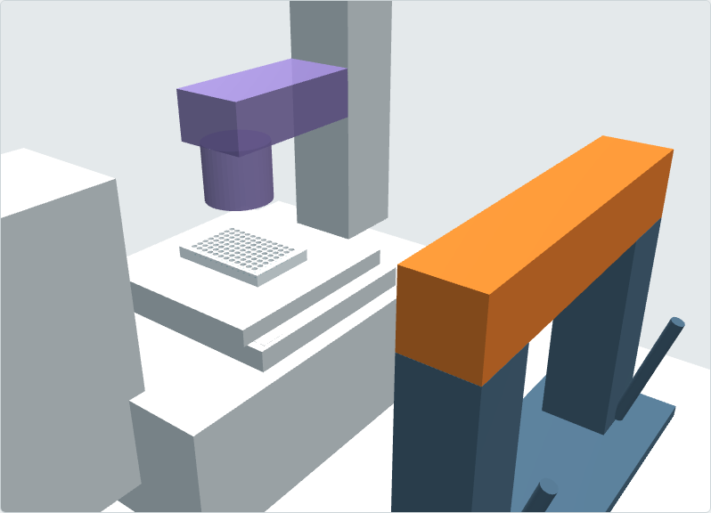
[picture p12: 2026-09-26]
docs/assembly_ja/img/step03.png

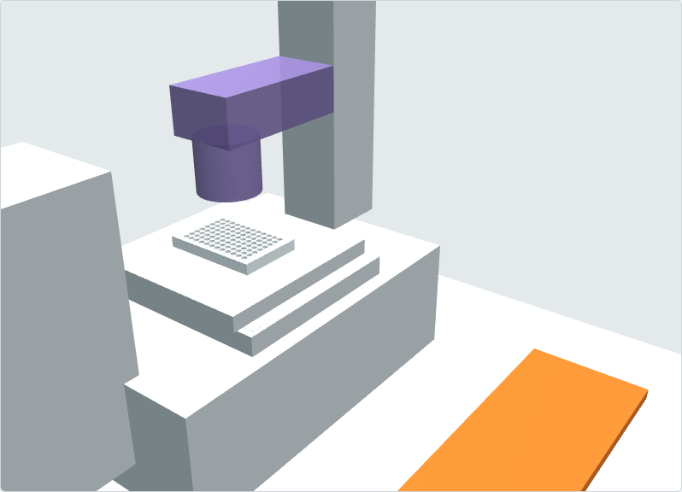
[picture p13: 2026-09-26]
docs/assembly_ja/img/step01.png

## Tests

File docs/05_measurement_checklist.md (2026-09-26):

<!-- GENERATED from docs/src/05_measurement_checklist.md by cad/render_docs.py - edit the source, not this file -->
# Measurement checklist for the real IX73 (do this before detailed CAD)

Reference frame: origin at the optical axis on the stage-insert top surface; +X operator's right, +Y away from the operator, +Z up. Photograph each measurement with a ruler in view. Enter the values in `cad/params.py`, change their status from `PH` to `MEAS`, and re-run `python tools/build_all.py`.

**Priority:** A = decides feasibility now; B = needed before brackets; C = nice to have.

**Freeze gate (10 items):** M1, M3, M4, M6, M7, M8, M10, M15, M19, M23 must be measured before any bracket or part number is frozen (`09_workflow_D1.md`). For W-B, also record the chosen motorised stage's envelope and travel.

| ID | Pri | Measurement | Currently in model | Why it matters |
|---|---|---|---|---|
| M1 | A | Optical-table surface → stage-insert top (plate resting plane) | 200 mm PH | post/beam height, overall frame |
| M2 | A | Table → top of plate (with the plate type actually used), and plate position on the stage insert (which corner is A1) | derived from SLAS | well coordinates, safe-Z |
| M3 | A | Stage outline (with IX3-SVR fitted), stage-insert opening, clips/holders protruding above the plate top | 232 × 240 MFR plain stage | arm clearance at pick height |
| M4 | A | Stage centre vs optical axis at the "reference position"; lockability of the stage | assumed centred | workflow D1 |
| M5 | B | Distances from optical axis to body front, rear, left, right faces | W/D MFR, position PH | tower placement |
| M6 | A | **Condenser model(s) available in the lab** (IX2-LWUCD? IX-ULWCD? MLWCD?) and outer diameter | Ø80 PH | decides the whole approach (`02_…`) |
| M7 | A | Condenser carrier / arm: width, lowest point, distance from axis to its left/right faces | ±45 mm PH | X support beam clearance (5 mm in model) |
| M8 | A | Condenser front-lens height above plate top with the condenser focused for 4× and 10× (real WD in use) | WD MFR + derived | clearance under the condenser. Enter the measured front height above the stage top as `COND_FRONT_Z_MEAS` in `cad/params.py`. |
| M9 | B | Illumination pillar: position, section, height; lamp housing envelope | PH | rear clearance |
| M10 | A | Illumination column tilted back: angle, and envelope of the column in the tilted position | PH | fallback option |
| M11 | B | Free height above the plate with the condenser raised to its top stop | – | capillary change position |
| M12 | B | Observation tube / eyepieces envelope (front), and any side port and camera on the left/right | PH | confirms no front/side conflict |
| M13 | B | IX3-SVR handle position and swing envelope (right side), focus knob positions both sides | PH | tower and hand access |
| M14 | B | Objective/turret: highest point below the stage at the largest objective used | PH | Z floor safety |
| M15 | A | Free table space to the right: x from the body side to the table edge; y extent; other equipment (incubator, controller, PC) | assumes ≥ +500 mm | frame footprint |
| M16 | B | Optical-table hole pattern (metric M6/25 or imperial ¼-20/1"), hole positions relative to the IX73 feet | – | base plate slots |
| M17 | A | Pump model(s) available, footprint, tubing port, control interface (RS-232/USB), and **its stop / inhibit input** (hardware input, dedicated digital input, or command only) | PH box | placement, fluidic line length; how the E-stop stops the pump (`06_electrical.md`) |
| M18 | A | **Illumination test**: hold a Ø10 mm rod 30–45 mm above focus, offset 0/4/8 mm from the axis, at 4× and 10×, condenser aperture open and closed; photograph the image | analytic estimate | confirms 8° vs 10–12° choice |
| M19 | A | **V1 plate lot check**: the plates actually bought are Corning 7007 (96-well U-bottom); measure well rim Ø, depth, plate height without lid, and A1 corner position in the holder. Other plate types are experimental and recorded only | Corning 7007 manufacturer drawing | V1 acceptance (target radius 0.5 mm), angle margin, safe-Z lower bound |
| M20 | C | Vibration: table isolation on/off; bench vs floated table | – | settle time before pick |
| M21 | B | Where the plate lid is placed during work | none | workflow |
| M22 | C | Cable routes to the PC/controller location | – | cable lengths |
| M23 | A | **Head height above the nose** (`HEAD_TOP_FROM_NOSE_MEAS`): with the real V1 holder (collet, nut, depth stop, seal, side port) mounted on the 8° block and the tubing clipped, the **vertical** distance from the collet nose to the highest point of the head | 22.2 mm = holder axial length 14 mm × cos θ + half the arm + 2.3 mm tubing (APX) | condenser margin and the safe-Z corridor upper bound fall 1 mm per mm; limit over the recommended settings ≈ 22.6 mm (`10_…`) |

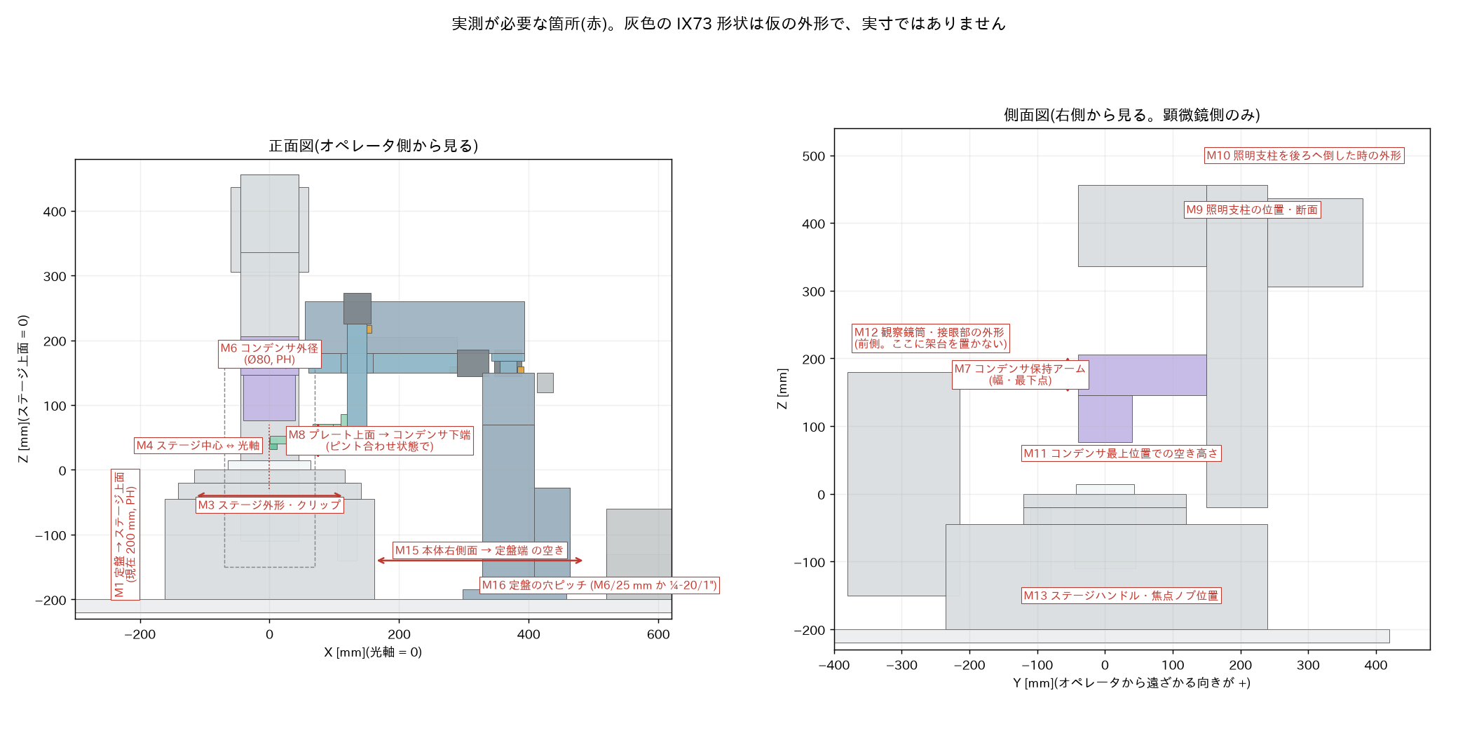
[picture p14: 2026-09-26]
docs/assembly_ja/img/measure_points.png

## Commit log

2026-09-25 Stage-1 spatial layout of external XYZ capillary picker around IX73
    Parametric build123d model (IX73 envelope, SLAS 96-well plate, condensers,
    side-tower frame, Y->X->Z stages, dog-leg arm, capillary, tubing), STEP
    assemblies for 0/8/30/45 deg heads, 96-well clearance sweep, well-access and
    illumination analysis, dimensioned views, interactive 3D viewer, literature
    review, architecture/actuator comparison, measurement checklist, electrical
    block diagram and source manifest with data-confidence tags.
    Claude-Session: https://claude.ai/code/session_01GPt433ziFBnW1Gi4L5kyyj
    [assembly_R08_IX-ULWCD.step, assembly_V00_IX-ULWCD.step, assembly_V30_IX-ULWCD.step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]
2026-09-26 Add capillary set for 100 um - 1 mm objects
    Three interchangeable OD classes (1.0/1.5/2.0 mm) with well-access check:
    8 deg approach keeps >=0.87 mm rim clearance up to OD 2.0.
    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
2026-09-26 D1 workflow comparison (stage-fixed vs stage-moving) and single source of truth
    - params.py derives the frame layout (arm, thin section, tower, posts, travel) per
    workflow; model/analysis/views read only from it (fixes stale POST_X/ARM_L).
    - Model: plate+stage move as a stage group; STEP assemblies per workflow.
    - Analysis: W-B sweep with the stage bringing each well to the axis, stage-travel
    corners at safe-Z, D1 metrics (observed wells, stage travel requirement).
    - Docs are templates (README.src.md, docs/src) rendered by cad/render_docs.py with
    numbers from cad/keynums.py; --check detects stale docs.
    - New docs/09_workflow_D1.md and d1_workflows figure; viewer workflow toggle.
    - Thin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
    [assembly_WA_R08_IX-ULWCD.step, assembly_WA_V00_IX-ULWCD.step, assembly_WA_V30_IX-ULWCD.step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]
2026-09-26 Add Japanese assembly guide with step renders and measurement-point figure
    - viewer step mode (#stepN) renders each assembly step with new parts highlighted
    - docs/assembly_ja: guide template + builder (numbers from keynums), measurement figure
    - posts end at the beam underside (removes overlap)
    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
    [assembly_WA_R08_IX-ULWCD.step, assembly_WA_V00_IX-ULWCD.step, assembly_WA_V30_IX-ULWCD.step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]
2026-09-26 Plate formats (6-96 well) with exchangeable angle blocks; auto-updating guide
    - PLATE_FORMATS and ANGLE_BLOCKS in params; format x angle check (rim, holder over
    plate, condenser at safe-Z, light obstruction) picks block and exposed length
    - 20 deg head added to the model; W-B exports 8/20/30 deg heads
    - docs/10_plate_formats_angle_blocks.md, formats_angle_blocks figure
    - guide: angle-block section, auto build info, placeholder list and changelog
    - tools/build_all.py regenerates everything; render_steps.js for guide renders
    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
    [assembly_WA_R08_IX-ULWCD.step, assembly_WA_V00_IX-ULWCD.step, assembly_WA_V20_IX-ULWCD.step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]
2026-09-26 Add pre-assembly action list, parts candidates; fix doc inconsistencies
    - docs/src/11_pre_assembly_actions_ja.md: measure / test / decide / order / fabricate
    / final-check list with freeze gate and dependency diagram
    - docs/parts: 38 candidate line items (candidates.csv, research_notes.md),
    rendered to docs/12_parts_candidates.md and into the Japanese guide
    - baseline workflow W-B is now the default; dimensioned views show W-B
    - angle set via blocks everywhere (no 0-12 deg arc slot); freeze gate is 8 items
    everywhere; actuator strokes from keynums; M-ID and lid-height fixes; guide
    step 7 parks at +X before raising Z; 45 deg evaluated but not in the block set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
    [assembly_WA_R08_IX-ULWCD.step, assembly_WA_V00_IX-ULWCD.step, assembly_WA_V20_IX-ULWCD.step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]
2026-09-26 Address full review: Z reference homing, head-top allowance, per-class angle blocks
    Critical
    - Z homes to a reference switch below the condenser (not the top); homing order
    Z-ref -> X park -> Y; Z above the reference only at park (fixes W-A keep-out too)
    - condenser margin includes the tubing allowance (HEAD_TOP_ALLOW); holder stack
    height is a freeze-gate item (M23) with the allowable maximum reported
    Major
    - angle-block recommendation per plate x capillary class, tilted-tip stand-off,
    reachable bottom area criterion, D8 for the 48-well large-OD case
    - light obstruction by ray test incl. the arm; required WD from the sweep
    - layout from catalogue strokes (anchored inner/lower ends); X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
    [assembly_WA_R08_IX-ULWCD.step, assembly_WA_V00_IX-ULWCD.step, assembly_WA_V20_IX-ULWCD.step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]
2026-09-26 Address issues #4-#10: V1 plate freeze, safe-Z corridor, head consistency, provenance, CI
    - #10: freeze V1 to Corning 7007 (PLATE_PROFILES, scope V1/experimental), target
    acceptance radius per capillary class, M19 in the freeze gate
    - #5: one physical Z reference switch; safe-Z corridor (lower/upper) per head,
    build fails when no corridor exists; viewer shows the corridor
    - #6: single head-height definition (HOLDER_AXIAL_LEN, head_top_from_nose,
    M23 = HEAD_TOP_FROM_NOSE_MEAS); exported CAD heads checked against it
    - #7: stage centring allowance and carriage moment tables; tip travel vs
    actuator stroke separated in docs and parts list
    - #8: break-away mount documented as repositioner,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
    [assembly_WA_R08_IX-ULWCD.step, assembly_WA_V00_IX-ULWCD.step, assembly_WA_V20_IX-ULWCD.step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]
2026-09-26 Review follow-up: single V1 target radius, mount wording, stroke metadata
    - V1_TARGET_RADIUS (0.5 mm) is the single source; the Corning 7007 profile's
    target radius is derived from it (was 1.0 mm); test added
    - breakaway_kinematic_mount note: kinematic repositioner, not a capillary
    force limiter; docs/02 heading renamed from "Collision fuse"
    - actuator notes derive catalogue stroke and tip travel from params.layout()
    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
    [assembly_WA_R08_IX-ULWCD.step, assembly_WA_V00_IX-ULWCD.step, assembly_WA_V20_IX-ULWCD.step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]
2026-09-26 Add part map: numbered figures linking parts, CAD, parts list, steps, measurements
    - docs/parts/part_map.py: single source for 27 numbered part groups (role,
    make/buy/existing, P01-P42, CAD names, related measurements) and the
    assembly steps (moved from viewer/build_viewer.py)
    - docs/13_part_map_ja.md and docs/assembly_ja/part_map_ja.html generated,
    with numbered overall and head close-up renders (viewer #partmap mode)
    - build --check and tests fail if a W-B CAD part or a parts-list ID is unmapped
    - Z reference switch now shown in assembly step 6; parts list uses FREEZE_GATE
    Claude-Session: https://claude.ai/code/session_01GPt433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
